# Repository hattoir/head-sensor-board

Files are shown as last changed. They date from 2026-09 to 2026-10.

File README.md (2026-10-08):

# 🧠 Serpens Head Sensor Board

> Prototype head sensor PCB for the Serpens snake-shaped pet robot.

Serpensの頭部に搭載するために設計している、
**試作用センサ基板**です。

XIAO ESP32S3 Senseを中心に、

- VL53L1X ToFセンサ ×2
- NSSW157T 白色LED ×2
- MOSFET PWM駆動
- I2C
- Test Points
- 外付けLEDヘッダ

をまとめています。

主な目的は、

- 床端・崖の検出
- 頭部周辺の距離センシング
- LEDによる表現・照明試験

です。

> ⚠️ 現在は設計・製造データ生成まで完了していますが、
> 実基板はまだ発注・製造していません。

---

## 📊 Current Status

| Area | Status |
|---|---|
| Specification | ✅ Complete |
| Schematic | ✅ ERC 0 |
| PCB Layout | ✅ Complete |
| Routing | ✅ Complete |
| DRC | ✅ 0 violations |
| 3D Render | ✅ Complete |
| Gerber / Drill | ✅ Generated |
| BOM | ✅ Generated |
| Manufacturing | ⚪ Not ordered |
| Hardware Verification | ⚪ Not tested |

---

## 🖼 PCB Preview

<!-- ここに今ある3Dレンダリング画像 -->

### Top / Angle View

Head Sensor Board

> ※ 実物写真ではなく、KiCad上の3Dレンダリングです。

---

## ⚙️ Main Components

- XIAO ESP32S3 Sense
- VL53L1X ×2
- NSSW157T ×2
- AO3400A / MOSFET
- I2C pull-up
- Test points

---

## 📐 Board

- Size: **44 × 28 mm**
- Layers: **2**
- M2 mounting holes ×2
- GND plane on both layers
- USB-C access from board edge
- ToF headers on long edges
- LED / external LED headers on right side

---

## 🔬 Verification

現在までに、

- ERC: 0 errors
- DRC: 0 violations
- Unconnected: 0
- Schematic / PCB mismatch: 0
- Silkscreen clearance check
- Gerber verification

を行っています。

ただし、
実機に接続しての電源・ToF・LED動作確認は未実施です。

---

> ## ⚠ 電源の運用上の注意（User 指示 2026-10-01。回路図の注記 H にも同じ内容）
> 1. **5V は試験用の選択肢で、既定は 3V3。** 5V にしたときの合計 **493 mA は USB 2.0 の 500 mA ぎりぎり**（余裕 7 mA）。XIAO の 5V ピンの電流能力は未確認。
> 2. **3V3 は、Wi-Fi 送信・撮影・LED 100 %・ToF ピークを同時にしない運用が必要。** **実機で XIAO の 5V 入力電流を測るまで。**（Seeed の条件不明の 0.65 A を上限と見ると 3V3 の合計は 808 mA = Seeed の「700 mA」の 115 %。[docs/spec.md](docs/spec.md) §4.3）

## 進み具合

| Stage | 内容 | 状態 |
|---|---|---|
| 1 | 仕様と部品表 | 完了（2026-10-01、承認済み） |
| 2 | 回路図と ERC（エラー 0） | 完了（2026-10-01、User 確認済み。ERC 0 件） |
| 3 | 外形と部品配置案（配線なし） | 完了（2026-10-01、User 確認済み） |
| 4 | 外形 44×28 mm、配線、DRC（違反 0・未接続 0・回路図との不一致 0）、3D ビュー、製造データ | **完了（2026-10-02）。製造データ（ガーバー・ドリル・位置ファイル・BOM、ZIP）は [gerbers/](gerbers/) に出した。User の最終確認待ちで、発注はしていない**（[docs/spec.md](docs/spec.md) §6・§7） |

## 配線後の配置（Stage 4）

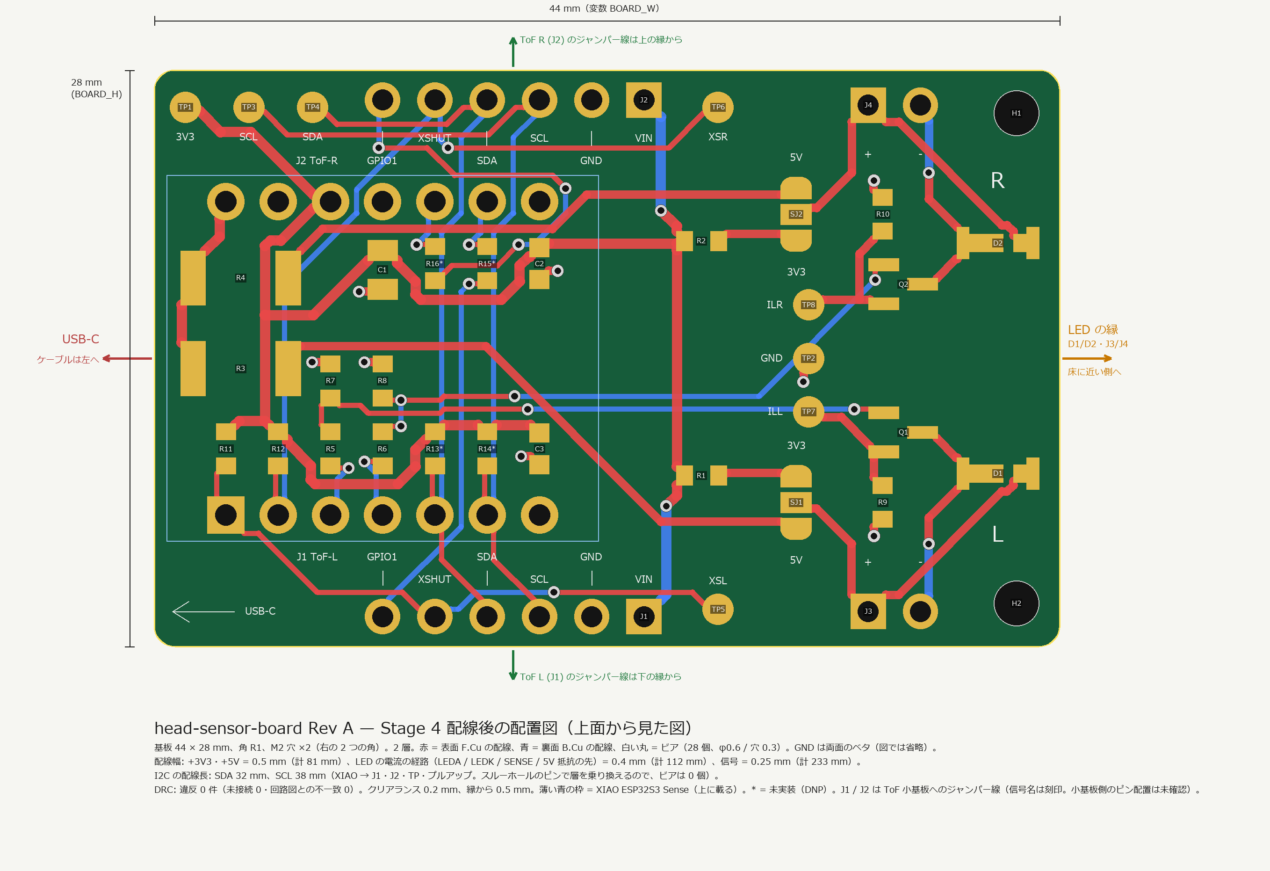
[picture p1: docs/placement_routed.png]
配線後の配置図


- **44 × 28 mm、角 R1、M2 穴 ×2**（右の 2 つの角、縁から 2.1 mm）。2 層。`python tools/make_board.py --width W --height H` で、外形・配置・配線・DRC まで作り直せる（[再生成と検証](#再生成と検証)）。
- **USB-C は左の縁**（左下に矢印と「USB-C」の刻印）、**LED（D1/D2）と外付け LED ヘッダ（J3/J4）は右寄りの縁**、**ToF ヘッダ（J1/J2）は上下の長辺の縁**（6 本の信号名を刻印）、TP は上面。**「L」「R」の刻印**あり。
- **下半分 = L チャンネル、上半分 = R チャンネル**（上面から見て USB-C を左にしたとき）。基板上の L/R はロボットの左右とは限らない（ジャンパー線で左右は自由に決められる）。
- 配線: **電源（+3V3・+5V）0.5 mm、LED の電流の経路 0.4 mm、信号 0.25 mm**。GND は両面のベタ。ビア 28 個。I2C の長さは SDA 32 mm・SCL 38 mm。
- **DRC: 違反 0 件**（クリアランス 0.2 mm・縁 0.5 mm・未接続 0・回路図との不一致 0。プロジェクトで「無視」にしていた 4 種の検査も有効にして 0 件）。[docs/drc_report.txt](docs/drc_report.txt)
- **刻印の検査**（`tools/check_board.py`）: 上面の刻印 137 個が、ランド・ほかの刻印と **0.15 mm 以上**、ヘッダの樹脂部（2.54 mm 角）と 0.05 mm 以上、XIAO の外形・基板の縁と離れている。**シルクの線は全部 0.15 mm 以上、文字の高さは 0.8 mm**（2026-10-05 に 0.12 → 0.15 mm に直した。発注先 4 社の公開仕様との照合 → [docs/fab_check.md](docs/fab_check.md)。**JLCPCB の標準の文字（高さ 1.0 mm 以上）だけは未達で、注文画面の「高精度の文字」を選べば通る**。PCBWay・Elecrow・Seeed Fusion は通る）。J1/J2 の信号名は樹脂部の外に 2 段で置き、奥の段には樹脂部の手前までの引き出し線を引いた。
- XIAO の下（ソケットの内側）に小さい部品を置き、裏面は GND ベタ。Sense 拡張ボード（カメラ・microSD）は XIAO の上面に載り、基板側の部品とは干渉しない（出っ張りは未確認。[docs/spec.md](docs/spec.md) §6.5）。

| | |
|---|---|
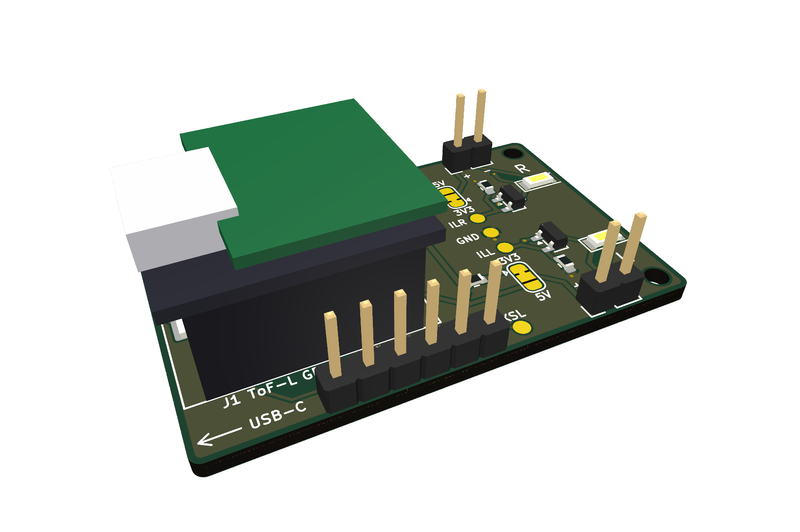
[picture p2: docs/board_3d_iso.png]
3D（斜め）
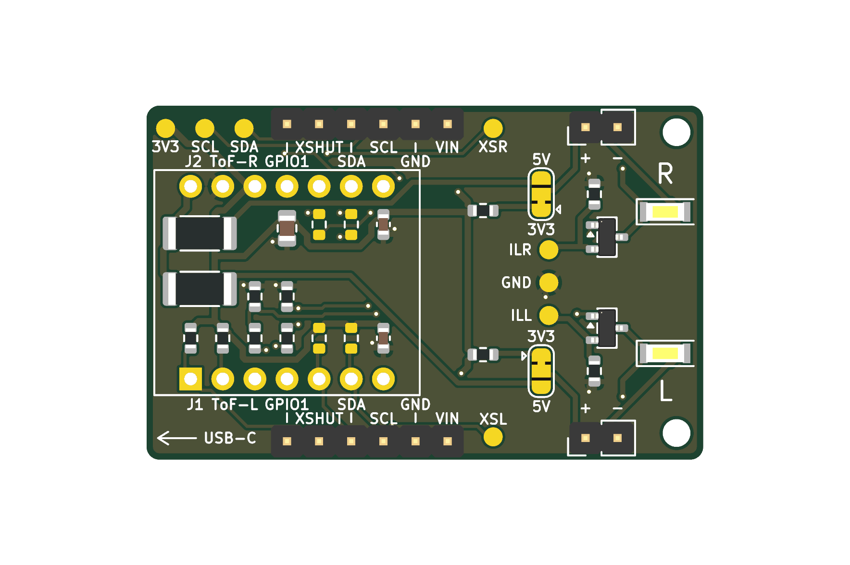
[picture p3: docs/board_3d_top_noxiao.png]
3D（XIAO なし）
|  |  |
| 斜め上から（XIAO・拡張ボードは**簡易な箱**。高さは仮） | 真上から（XIAO を外した状態） |

そのほか: [層ごとの配線](docs/routing_layers.png)（表面 F.Cu・裏面 B.Cu）、[3D 真上](docs/board_3d_top.png)、[3D 裏面](docs/board_3d_bottom.png)。

## ToF 小基板のピン配置と、ジャンパー線の対応表（**現物が届いたら埋める**）

J1 / J2 の 6 本は、ToF 小基板（VL53L1X、Amazon B083Z316NC）へジャンパー線でつなぐ。**小基板のピン配置は販売ページに記載がなく、未確認。** ヘッダの並び（上面に信号名を刻印）は仮で、**小基板の並びが違っても基板の作り直しは要らない**（線でつなぎ替える）。J1 = ToF L（下の縁）、J2 = ToF R（上の縁）。pin1 は右端（上面から見て、VIN）。

### J1 / J2 の向き（Stage 3 から 180° 回した理由）と確認結果

- **ピン 1（四角いパッド）は右端**（上面から見て USB-C を左にしたとき）。刻印の並びは**右から** VIN, GND, SCL, SDA, XSHUT, GPIO1（左から読むと GPIO1, XSHUT, SDA, SCL, GND, VIN）。J1 と J2 は同じ向き・同じ x（ピン 1 = 基板の左端から 23.8 mm）。
- Stage 3 ではピン 1 が左端だった。**Stage 4 で 180° 回した理由**: XIAO では SDA（D4）が SCL（D5）の左にある。ヘッダも SDA が SCL の左になる向きにすると、I2C の線が交差せずに、層の乗り換え（ビア）も減る。ヘッダの**信号の割り当て（pin1 = VIN … pin6 = GPIO1）は回路図のまま変えていない**（並べ替えは物理的な向きだけ）。ジャンパー線で小基板につなぐので、向きは線の取り回しにしか影響しない。
- 確認（`python tools/check_board.py`、基板を直接読む）: J1/J2 の 6 パッドすべてで、**基板のネット = 回路図のネット = 刻印の名前**（pin1 +3V3/VIN、pin2 GND、pin3 SCL、pin4 SDA、pin5 XSHUT_L/R、pin6 TOF_L_INT/TOF_R_INT/GPIO1）。四角いパッドは pin1 だけ。

### 小基板の仕様（現物で確認して埋める）

| 項目 | 値 | 確認 |
|---|---|---|
| 基板上の印字（ピンの名前、端から順に） | （現物で確認） | 🔴 未確認 |
| ピンの数・ピッチ・オス/メス | （現物で確認） | 🔴 未確認 |
| 電源電圧 | 3.3〜5 V（商品ページの記載） | 🟡 |
| 基板上のプルアップ（SDA / SCL / XSHUT）、レギュレータ、レベルシフタの有無 | （現物で確認） | 🔴 未確認 |
| I2C アドレス | ST のデータシートの既定は 0x29（7 bit）。**小基板で変わるかは未確認** | 🟡 |

### 対応表（J1 / J2 のピン ↔ 小基板のピン）

| J1 / J2 のピン | 基板の信号名 | つなぎ先 | 小基板のピン（印字）→ **現物で記入** | ジャンパー線 | メモ |
|---|---|---|---|---|---|
| 1 | VIN | XIAO の 3V3 | （　　　　） | （　　　　） | 小基板が 3.3〜5 V 対応なので 3V3 を使う。**VIN と GND を逆につながない**（小基板の保護は未確認） |
| 2 | GND | GND | （　　　　） | （　　　　） | |
| 3 | SCL | I2C SCL（D5） | （　　　　） | （　　　　） | プルアップは基板側 R14（3.3 kΩ、既定は未実装）か小基板側 |
| 4 | SDA | I2C SDA（D4） | （　　　　） | （　　　　） | 同 R13（既定は未実装） |
| 5 | XSHUT | J1: XSHUT_L（D0）／J2: XSHUT_R（D1） | （　　　　） | （　　　　） | 10 kΩ で 3V3 にプルアップ済み |
| 6 | GPIO1 | J1: R15 経由で D8／J2: R16 経由で D9 | （　　　　） | （　　　　） | R15/R16（0 Ω）は**既定で未実装**（つながない）。割り込みを使うときだけ実装 |

**2 個の小基板は I2C アドレスが同じ**なので、XSHUT で 1 個ずつ起動して、片方のアドレスを変える（[docs/spec.md](docs/spec.md) §3）。

## フォルダ構成

| 場所 | 中身 |
|---|---|
| （直下） | KiCad プロジェクト（`.kicad_pro` / `.kicad_sch` / `.kicad_pcb`、`sym-lib-table` / `fp-lib-table`） |
| `.ai/` | 閉ループの記録（`CURRENT_HANDOFF.md`、`PROJECT_STATE.json`、`TASK_GRAPH.json`、`DECISIONS.jsonl`、`EXPERIMENTS.jsonl`、`EVIDENCE.jsonl`。追記専用の `.jsonl`）。次のセッションはここから再開する |
| `docs/` | [spec.md](docs/spec.md)（仕様・計算・配置・配線・検証）、[fab_check.md](docs/fab_check.md)（発注先の公開仕様との照合）、[bringup_plan.md](docs/bringup_plan.md)（届いてからの確認手順 = Human Gate）・[bringup_nets.md](docs/bringup_nets.md)（導通の確認表）、[bom.md](docs/bom.md)・`bom.csv`（部品表。**Stage 2 のまま**。BOM の出力時に再生成）、`erc_report*.txt`・`drc_report.txt`、回路図 PDF、配線後の配置図・層ごとの配線・3D ビュー（PNG）、`routes.json`（配線の結果）、`led_budget_output.txt` |
| `libs/` | 自作のシンボル・フットプリント（**KiCad 標準ライブラリに無いものだけ**。下の「ライブラリの出典」） |
| `3dmodels/` | 3D ビュー用の**簡易モデル**（`.wrl`。XIAO + Sense 拡張ボード、LED の箱）。`tools/gen_3d.py` で生成。見た目の確認用 |
| `gerbers/` | **製造データ**（ガーバー、ドリル、位置ファイル、BOM、`head-sensor-board_gerbers.zip`、README）。2026-10-02 に出した。**発注はしていない**（User の最終確認のあと）。中身の説明は [gerbers/README.md](gerbers/README.md) |
| `tools/` | 計算・生成・検証のスクリプト（下の「再生成と検証」） |

## 数値・部品名の出典

確認状態: ✅ 原本（データシート・公式図面）で確認 ／ 🟡 販売ページ・Wiki で確認 ／ 🔴 未確認・仮定。**確認できていないものは、`docs/spec.md` の各表に「未確認」と書いてある。**

| 対象 | 出典 | 確認 |
|---|---|---|
| NSSW157T（Nichia）: 外形 3.0×1.4×0.52、VF、IF max、推奨ランド | [Nichia STS-DA1-1913（秋月配布 PDF）](https://akizukidenshi.com/goodsaffix/nssw157t.pdf)、[秋月 116884](https://akizukidenshi.com/catalog/g/g116884/) | ✅ |
| AO3400A（Alpha & Omega）: VGS(th)、RDS(on) @2.5 V、SOT-23 | [AOS データシート Rev 3.1](https://www.aosmd.com/res/data_sheets/AO3400A.pdf) | ✅ |
| Si2302CDS（Vishay）: VGS(th)、RDS(on) @2.5 V、1=G 2=S 3=D | [Vishay 68645（S12-2336 Rev D）](https://www.vishay.com/docs/68645/si2302cds.pdf) | ✅ |
| VL53L1X（ST）: AVDD 2.6〜3.5 V、消費電流、XSHUT・I2C・既定アドレス、最短 4 cm | ST DS12385 Rev 8（[複製 PDF](https://www.makerguides.com/wp-content/uploads/2024/10/VL53L1X-Datasheet.pdf)。ST 公式サイトの版では未照合） | ✅（複製） |
| ESP32-S3: Wi-Fi 送信ピーク 340 mA、GPIO の IOH/IOL、VOH、GPIO3 ストラッピング | [Espressif ESP32-S3 Datasheet v2.2](https://www.espressif.com/sites/default/files/documentation/esp32-s3_datasheet_en.pdf)（表 5-7・表 5-4・§3.4） | ✅ |
| XIAO ESP32S3: ピン配置、GPIO 番号、3V3 出力 700 mA、Webcam の消費電流、Sense が使う GPIO | [Seeed wiki](https://wiki.seeedstudio.com/xiao_esp32s3_getting_started/)（PDF のデータシートは見つからず） | 🟡 |
| XIAO の穴パターン（ピッチ 2.54、行間隔 15.25、穴 φ1.02、外形 21×17.8） | [Seeed "XIAO Series Package and PCB Design" p.7](https://www.seeedstudio.com/blog/wp-content/uploads/2022/08/Seeed-Studio-XIAO-Series-Package-and-PCB-Design.pdf)（シリーズ共通図。S3 個別ではない） | ✅（共通図） |
| VL53L1X 小基板（Amazon B083Z316NC）: 12×17×3.2 mm、3.3〜5 V | [商品ページ](https://www.amazon.co.jp/dp/B083Z316NC)。**ピン配置・プルアップ・アドレスの記載なし** | 🔴 |
| 頭の外形 幅 100 / 高さ 74 / 長さ 78 mm、ToF・LED の位置 | `serpens/ai-shared/design-state.md`、`serpens/docs/design/tof_board_placement_2026-09-30.md`（Design の概念値 = CAD_CONCEPT / ASSUMED） | 🔴（概念値） |
| T6 / T4 の試験の内容 | `serpens/ai-shared/HARDWARE_TODO.md` HT-005 / HT-011、HG-H2 の `hardware_test_plan.md`・`tof_cliff.md`（Engineering の worktree `agent/engineering-h1-j1`、未マージ） | 🟡 |

## ライブラリの出典

`libs/` にあるのは、KiCad 標準ライブラリに無い（または標準を少し変えた）7 点だけ（`python tools/gen_libs.py` で生成）。

| 名前 | 種類 | 理由 | 出典 |
|---|---|---|---|
| `XIAO_ESP32S3` | シンボル（14 ピン。電源ピンを上下に置いた表示。ピン番号は実物のまま） | 標準ライブラリに XIAO ESP32S3 が無い | ピン配置は Seeed wiki |
| `ToF_Header_1x06` | シンボル（ピン名つき。**並びは仮 = 未確認**） | ピン名（VIN, GND, SCL, SDA, XSHUT, GPIO1）を回路図に出すため | 自作 |
| `Q_NMOS_GSD` | シンボル（SOT-23 の 1=G 2=S 3=D） | 標準の `Device:Q_NMOS` はピン番号が D/G/S の文字で、SOT-23 のパッド番号と合わない | 図形は KiCad 標準 `Device:Q_NMOS` を流用、ピン番号だけ数字に |
| `XIAO_ESP32S3_THT_2x7_P2.54mm` | フットプリント（穴パターン） | 標準には表面実装用の `RF_Module:MCU_Seeed_ESP32C3` しか無く、2.54 mm の穴パターンが無い | Seeed 公式図面 p.7（行間隔 15.24 mm = 図面の 15.25 を 0.6 in に丸めた、穴 φ1.02、パッド φ1.8）。**コートヤードはピン列の帯だけ**（XIAO の下に小さい部品を置くため。Stage 3） |
| `TestPoint_Pad_D1.5mm_NoSilk` | フットプリント（TP） | 標準の `TestPoint:TestPoint_Pad_D1.5mm` の銀色の輪（半径 0.95 mm）が、近くに置く名前の刻印と重なるため | KiCad 標準 `TestPoint_Pad_D1.5mm` から輪だけ除いた（パッド φ1.5、コートヤード 半径 1.05）。Stage 3 |
| `PinHeader_1x06_P2.54mm_NoSilk` | フットプリント（J1/J2。ToF ヘッダ） | 標準の `Connector_PinHeader_2.54mm:PinHeader_1x06_P2.54mm_Vertical` の上面シルクの外枠が、6 本の信号名の刻印と重なるため | KiCad 標準から**上面シルクの外枠（線・四角）だけ除いた**（ランド・穴・コートヤード・Fab・3D は標準のまま）。Stage 4 |
| `LED_Nichia_NSSW157T` | フットプリント（T 字のランド） | 標準ライブラリに同寸法のものが無い | Nichia STS-DA1-1913 p.4–5（全長 4.0、カソード 0.6+1.66、ギャップ 0.5、アノード 0.64+0.6、高さ 1.55/0.86） |

3D モデル: 標準ライブラリにある部品（ピンヘッダ、抵抗、MOSFET など）は標準のモデル。**XIAO + Sense 拡張ボードと NSSW157T は `3dmodels/` の簡易な箱**（高さは仮。見た目の確認用で、寸法の根拠にしない）。

## 再生成と検証

```bash
python tools/led_budget.py        # LED 電流・3V3/5V の総電流の計算（docs/led_budget_output.txt）
python tools/gen_libs.py          # 自作ライブラリ（libs/）と sym-lib-table / fp-lib-table
python tools/gen_3d.py            # 簡易 3D モデル（3dmodels/）
python tools/gen_schematic.py     # 回路図（※KiCad で手直しした後は実行しない。手直しが消える）
python tools/check_netlist.py     # ネットリストを期待と照合、回路図のピン番号がフットプリントのパッドに存在するか
python tools/make_board.py [--width 44 --height 28] [--reuse-routes]
                                  # 外形・配置（gen_pcb.py）→ 自動配線（route.py、numpy + scipy）→ トラック・ビア・GND ベタ（apply_routes.py）→ DRC。
                                  # ※既存の基板を作り直す（KiCad で手で直した配線は消える）。約 30 秒
                                  # --reuse-routes: ランドの位置を変えず刻印だけ直したとき、配線をやり直さない（DRC で整合を確かめる）。自動配線は約 1〜10 分（CPU が空いていれば 1 分以内）
"C:/Program Files/KiCad/10.0/bin/python.exe" tools/check_board.py   # J1/J2 のネット・パッド・刻印の照合、刻印のすきまの検査（問題があれば終了コード 1）
"C:/Program Files/KiCad/10.0/bin/python.exe" tools/render_routed.py   # 配線後の配置図・層ごとの配線（docs/*.png）
python tools/render_3d.py         # KiCad の 3D ビュー（docs/board_3d_*.png）
python tools/make_outputs.py [--bom]   # ERC・DRC・回路図 PDF・BoardRepo 用 zip（--bom で BOM も）
python tools/make_fabrication.py  # gerbers/（ガーバー・ドリル・位置ファイル・BOM・ZIP）。**User の確認のあとにだけ**
python tools/verify_gerbers.py    # 出力した ZIP を別のライブラリ（gerbonara）で読み直して、基板と照合（pip install gerbonara）
python tools/compare_gerbers.py --current   # gerbers/ が今の基板から作り直した図形と同じか（古くなっていないか）。2 つの ZIP / git の ref の比較にも使える
"C:/Program Files/KiCad/10.0/bin/python.exe" tools/check_fab_rules.py [--md docs/fab_check.md]   # 発注先 4 社の公開仕様（tools/fab_rules.json）との照合
python tools/gen_bringup_tables.py   # 導通の確認表 docs/bringup_nets.md（回路図から）
python tools/run_all_checks.py    # 上の検査を全部まとめて回す（何も書き換えない。発注の前に）
```
KiCad は `C:/Program Files/KiCad/10.0/bin/kicad-cli.exe`（PATH には入っていない）。`tools/pcb_template.kicad_pcb` は空の基板（層・設定だけ。`gen_pcb.py` が毎回ここから作る）。
自動配線は KiCad の Python に scipy が無いため、基板の形状を `docs/placement_geometry.json` に書き出し → システムの Python で配線 → `docs/routes.json` → KiCad の Python で基板に書き戻す、の 3 段。

## BoardRepo について

- BoardRepo は「アップロードのたびに番号つきの版ができる」方式で、閲覧・MCP は OAuth のサインインが要る（[boardrepo.com](https://boardrepo.com)）。**Agent 側からは取り込みを確認できない。User が手動でアップロードする。**
- `snake-main-board` の GitHub リポジトリにも、BoardRepo の Webhook・チェック・コミットステータスは残っていない（確認済み）。
- **アップロード用の束**: `C:\2026\Serpens_Home AI\head-sensor-board_upload.zip`（`tools/make_outputs.py` が作る。Git には入れない）。中身: `.gitignore`、`README.md`、`.kicad_pro`、`.kicad_sch`、`.kicad_pcb`（**Stage 4: 44×28 mm、配線済み・GND ベタ。ガーバーではない**）、`sym-lib-table`、`fp-lib-table`、`libs/`（自作ライブラリ）、`3dmodels/`（簡易 3D モデル）。別フォルダに展開して、ERC 0 件・DRC 0 件になることを確認する（make_outputs 後に実施）。
- **アップロードして表示できたかは User の確認が要る。**

## 注意

- `*-backups/`、`fp-info-cache`、`*.kicad_prl`、ロックファイル、自動保存、`*_upload.zip` は Git に入れない（`.gitignore`）。
- このフォルダは、親の `serpens`（ロボット制御のリポジトリ）とは**別の Git リポジトリ**（入れ子）。親側は `.git/info/exclude` で無視している。`snake-main-board` とも別。

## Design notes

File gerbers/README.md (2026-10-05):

# gerbers/ — head-sensor-board Rev A の製造データ

**未発注。User の最終確認のあとに発注する**（発注は Agent はしない）。Stage 4 の PNG を User が確認した後に `python tools/make_fabrication.py` で作った（KiCad 10.0.1 の `kicad-cli`）。
基板を直したら、`python tools/make_board.py` → `python tools/make_outputs.py --bom` → `python tools/make_fabrication.py` の順で作り直す（このフォルダのファイルは毎回消して作り直される。手で直さない）。

## 発注先に渡すもの

**`head-sensor-board_gerbers.zip`**（ガーバー 8 層 + ジョブファイル + ドリル 2 本 = 11 ファイル）。

## ファイル

| ファイル | 内容 |
|---|---|
| `*-F_Cu.gtl` / `*-B_Cu.gbl` | 表・裏の銅（GND のベタを含む） |
| `*-F_Mask.gts` / `*-B_Mask.gbs` | 表・裏のレジスト開口（ランドと同寸。ビアはふさぐ） |
| `*-F_Silkscreen.gto` / `*-B_Silkscreen.gbo` | 表・裏のシルク（表: 部品の枠・信号名・L/R・USB-C、裏: 凡例） |
| `*-F_Paste.gtp` | 表のはんだペースト（ステンシルを作るときだけ。手はんだなら不要） |
| `*-Edge_Cuts.gm1` | 外形（角 R1 の長方形） |
| `*-PTH.drl` / `*-NPTH.drl` | ドリル（Excellon、mm）。PTH = めっきあり、NPTH = めっきなし（M2 の取付穴） |
| `*-job.gbrjob` | ジョブファイル（層の構成・寸法） |
| `*-PTH-drl_map.pdf` / `*-NPTH-drl_map.pdf` | ドリルの位置図（目で確かめる用。発注先には要らない） |
| `head-sensor-board_pos.csv` | 位置ファイル（**表面実装で、実装するもの**だけ。DNP の R13〜R16 は含まない。mm、原点は基板の左下、Y は上が +） |
| `head-sensor-board_BOM.csv` | BOM（`docs/bom.csv` と同じ。読みやすい版は `docs/bom.md`） |
| `SHA256SUMS.txt` | 各ファイルのハッシュ（手元で改変していないことの確認用） |

**原点はすべて基板の左下**（ガーバー・ドリル・位置ファイルで共通）。

## 基板の仕様（発注フォームに入れる値。**発注先の仕様との照合は User が行う**）

| 項目 | 値 |
|---|---|
| 層数 | 2 層 |
| 寸法 | 44.0 × 28.0 mm（角 R1.0） |
| 厚み | 1.6 mm |
| 銅厚 | 基板データには指定なし。標準の 1 oz（35 µm）を想定（線の許容電流の目安もこれ） |
| 表面処理 | 指定なし（はんだ付けは手作業。XIAO・ヘッダのスルーホールと 0603 / 2010 / SOT-23 / NSSW157T） |
| 最小線幅 / 最小間隔 | 使った線幅は 0.25 / 0.4 / 0.5 mm（設計の下限 0.2）、間隔 0.2 mm 以上 |
| 銅と外形の距離 | 0.5 mm 以上 |
| ビア | 外径 0.6 mm / 穴 0.3 mm、レジストでふさぐ（テンティング） |
| 穴 | PTH φ0.3 mm × 28、PTH φ1 mm × 16、PTH φ1.02 mm × 14、NPTH φ2.2 mm × 2 |
| レジスト | 開口はランドと同寸（拡張 0）。多くの発注先は自分で拡張をかける。色は任意 |
| シルク | 線幅 **0.15 mm**（部品の枠を含む全部）、文字の高さ **0.8 mm**。**JLCPCB の標準は文字の高さ 1.0 mm 以上なので、JLCPCB で発注するときは注文画面の「高精度の文字」（0.8 mm 以上）を選ぶ**（追加費用の有無は未確認）。PCBWay・Elecrow・Seeed Fusion は 0.8 mm・0.15 mm で可。**4 社の公開仕様との照合は `docs/fab_check.md`**（2026-10-05 に公開ページから取った値。注文して確かめたものではない） |
| 数量 | User が決める |

## 注意

- **NSSW157T（D1/D2）はリフローかホットエアで付ける部品**（フットプリントの注意書きどおり。樹脂を押さない）。
- J1/J2 は ToF 小基板へのジャンパー線用のヘッダ。**小基板のピン配置は未確認**（README の対応表を現物で埋める）。信号名のシルクと基板の配線は、回路図と一致することを確認済み（`tools/check_board.py`）。
- 検証: `python tools/verify_gerbers.py`（KiCad とは別の gerbonara で、zip の中身を読み直して、外形・ドリルの位置と径・銅の抜けを基板と照合する。`pip install gerbonara` が要る）。`python tools/compare_gerbers.py --current` は、このフォルダが今の基板から作り直したものと同じ図形か（古くなっていないか）を確かめる。`python tools/run_all_checks.py` で全検査をまとめて回せる。結果は `docs/spec.md` §7。
- 届いてからの手順（外観・導通・初回通電・LED 電流・ToF）は `docs/bringup_plan.md`。

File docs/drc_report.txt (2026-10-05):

** Drc report for head-sensor-board.kicad_pcb **
** Created on 2026-10-05T18:53:41 **
** Report includes: Errors, Warnings, Exclusions **

** Found 0 DRC violations **

** Found 0 unconnected pads **

** Found 0 Footprint errors **

** Ignored checks **
    - Tuning profile track geometries

** End of Report **

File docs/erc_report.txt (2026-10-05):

ERC report (2026-10-05T18:53:34, Encoding UTF8)
Report includes: Errors, Warnings, Exclusions

***** Sheet /

 ** ERC messages: 0  Errors 0  Warnings 0

 ** Ignored checks:
    - Global label only appears once in the schematic
    - Four connection points are joined together
    - SPICE model issue
    - Assigned footprint doesn't match footprint filters

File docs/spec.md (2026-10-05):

# head-sensor-board — 仕様と部品表（Stage 4 更新版）

**Floor Watch の「頭のセンサー基板（試作用）」。** ToF の崖判定（HG-H2 の T6-1〜T6-4）と、斜め LED の追試（T4）に使う。**本番の基板ではない。**
状態: **Stage 4（44×28 mm、配線、DRC 違反 0）+ 製造データ（`gerbers/`）を出した（2026-10-02）。User の最終確認待ちで、発注はしていない。** 回路図は ERC 0。ToF 小基板のピン配置が未確認でも、ジャンパー線でつなぐので基板のガーバーは出せる（User 指示 2026-10-01）。

確認状態の印: ✅ 原本（データシート・公式図面）を読んで確認 ／ 🟡 販売ページ・Wiki で確認（原本は未確認）／ 🔴 未確認・仮定 ／ ⚪ 資料に記載なし

## 運用上の注意（User 指示 2026-10-01。README と回路図の注記 H にも同じ文を残した）

1. **5V は試験用の選択肢で、既定は 3V3。** 5V にしたときの合計 **493 mA は USB 2.0 の 500 mA ぎりぎり**（余裕 7 mA）。5V の取り出しは、半田ジャンパー SJ1/SJ2 の 5V 側パッドだけ（既定では開放）。XIAO の 5V ピンの電流能力は未確認。
2. **3V3 は、Wi-Fi 送信・撮影・LED 100 %・ToF ピークを同時にしない運用が必要。** 実機で XIAO の 5V 入力電流を測るまで（§4.3。Seeed の条件不明の 0.65 A を上限と見ると 808 mA = 700 mA の 115 %）。
3. **ToF 小基板のピン配置は未確認**（ヘッダの並びは仮）。ジャンパー線でつなぐので、並びが違っても基板は作り直さない（README の対応表を現物で埋める）。

## 0. Stage 1 からの変更点（User の回答 2026-10-01 を反映）

| # | User の回答 | この版での扱い |
|---|---|---|
| 1 | 外形 **40×25 mm**（角 R1、M2 穴 2 個）、変数で作り直せるように。頭（幅 100 × 高さ 74 × 長さ 78 mm、`design-state.md` の Bean 頭）に収まる。**ToF は基板に直付けせず、ジャンパー線で離して置く**（1×6 ヘッダから引き出す） | 外形は Stage 3 で `BOARD_W`/`BOARD_H` の変数で作る。ToF は 1×6 ヘッダ（J1/J2）+ ジャンパー線 12 本 |
| 2 | **高さ 6 mm 以下は LED だけ**。LED は基板上（D1/D2）+ 外付け用ヘッダ（L/R 各 2 本: +, −）。ほかの部品は制限なし | D1/D2（0.52 mm ✅）と、外付けヘッダ J3/J4 を追加。§6 |
| 3 | ToF のピン配置は現物が届くまで確定しない。**Stage 3 まで進め、ガーバーは出さない**。並びは仮、README に「未確認」 | シンボルとヘッダの並びを「仮（PLACEHOLDER）」と明記。README・回路図・BOM にも書いた |
| 4 | LED は 3V3・20 Ω（公称 約 30 %）で進める。**LED の電源を半田ジャンパーで 3V3（既定）/ 5V に切替**。5V 側の抵抗は 1206 以上で再計算。MOSFET のゲートが 3.3 V ロジックで駆動できることを確認 | SJ1/SJ2 + R3/R4（**33 Ω 2010**）。§4。MOSFET は AO3400A / Si2302CDS の原本で確認（§4.4） |
| 5 | 3V3 の電流の合計を、Wi-Fi・カメラのピークも含めて再計算 | §4.3 |
| 6 | GPIO 割り当ては承認（D0=XSHUT_L, D1=XSHUT_R, D2=LED_L PWM, D3=LED_R PWM, D4=SDA, D5=SCL, D6/D7=UART 予約、5V ピンは未接続）。integration-log に ENTRY（TO: Engineering） | §3。ENTRY-K-0001 |
| 7 | 追加購入（MOSFET ×2、抵抗・コンデンサ、ピンソケット・ピンヘッダ）は承認。品番・価格は User が調べる | [bom.md](bom.md)（型番・パッケージ・定格を書き出した） |
| 8 | **Stage 4（2026-10-01）**: 外形は **44×28 mm**（Stage 3 の 40×25 から。余裕ができた）、L/R・USB-C・J1/J2 の信号名を刻印、Sense 拡張ボードの張り出しを確認、穴の位置はそのまま、ToF のピン配置が未確認でもガーバーは止めない | §6 |

**解釈の注意（2 点）**
- **「5V ピンは未接続」と「LED 電源に 5V も選べる」は、そのままだと両立しない。** そこで「XIAO の 5V ピンは、半田ジャンパー SJ1/SJ2 の 5V 側パッドにだけつながる（既定では開放 = 電気的には未接続）」と解釈した。5V ピンを LED に使う場合だけ、User が半田でつなぐ。この解釈が違えば指示してほしい。
- Stage 1 の LED 電流は 公称 23.7 mA だったが、MOSFET の Rds(on) の仮定を 0.05 → 0.075 Ω（Si2302CDS の最大）に直したため **23.6 mA** になった（最小/最大は同じ 8.5 / 38.8 mA）。訂正ではなく仮定の更新。

## 1. 仕様

| 項目 | 内容 |
|---|---|
| 電源 | **既定: XIAO の 3V3 ピンだけ**。5V ピンは SJ1/SJ2 の 5V パッド（既定では開放）だけにつながる |
| マイコン | XIAO ESP32S3 Sense（U1）を、2×7 のピンソケット（またはピンヘッダ）で載せる。直付けしない。2.54 mm ピッチ、穴の行間隔 15.24 mm |
| ToF | VL53L1X 小基板 ×2。**1×6 ヘッダ J1/J2（VIN, GND, SCL, SDA, XSHUT, GPIO1）からジャンパー線で引き出す**（並びは仮）。XSHUT を GPIO から個別制御。GPIO1 は 0 Ω リンク（DNP）で D8/D9 につなげる |
| LED | NSSW157T ×2（D1/D2、基板上）。電流制限抵抗 + N-ch MOSFET でスイッチ、GPIO から PWM 調光。**外付け LED 用ヘッダ J3/J4（pin1 = +、pin2 = −）**。D1/D2 か外付けの**どちらか一方**を使う（両方だと電流を分け合う） |
| LED の電源 | 各チャンネル 3 パッドの半田ジャンパー（SJ1/SJ2）。**既定は 1-2 をつないだ状態 = 3V3（R1/R2 = 20 Ω 0603）**。5V にするときは 1-2 の橋を切り、2-3 をはんだでつなぐ（R3/R4 = 33 Ω 2010 は実装済み） |
| I2C プルアップ | R13/R14（3.3 kΩ）を置き、**既定は未実装（DNP）**。XSHUT のプルアップ（10 kΩ）は実装 |
| テストポイント | TP1 3V3、TP2 GND、TP3 SCL、TP4 SDA、TP5 XSHUT_L、TP6 XSHUT_R、TP7 ILED_L、TP8 ILED_R（電流の電圧 = 1 mV/mA） |
| 基板 | 2 層、1.6 mm。**外形 44×28 mm（角 R1、M2 穴 2 個）、変数で作り直せるように**（Stage 3 は 40×25）。KiCad 10.0.1 |

**LED チャンネルの回路（L / R 同じ）**
```
 +3V3 ─ R1(20Ω 0603) ─┐ 1
                       SJ ─2─ LEDA ─┬─ D(NSSW157T) ─┬─ LEDK ─ Q(AO3400A).D
 +5V  ─ R3(33Ω 2010) ─┘ 3           └─ J(+)          └─ J(−)            G ← 220Ω ← GPIO(PWM)、100kΩ で GND
                                                                          S ─ SENSE ─ R(1Ω) ─ GND   （TP ILED = SENSE）
```
J3/J4 のピンは抵抗の**あと**のノード（電流制限済み）。**J3/J4 の + と − を短絡しない**（R1 が約 0.49 W、R3 が約 0.71 W を消費して焼ける）。

## 2. 読んだ資料

| 資料 | 分かったこと |
|---|---|
| `serpens/ai-shared/design-state.md` | 頭は Bean 形: **幅 100 × 高さ 74 × 長さ 78 mm**（概念値。CAD_CONCEPT / ASSUMED）。ToF 小基板は横スキッド前端「肉球」（\|y\| 37.8〜49.8、z 3.0〜6.2）、LED は同じ前端（X −228、\|y\| 40、Z 4.5）。**基板の寸法制限の記載はない** → User が 40×25 mm で承認 |
| `serpens/ai-shared/interface-contract.md` | 役割分担の取り決めだけ。寸法の記載なし |
| `serpens/ai-shared/HARDWARE_TODO.md` HT-005 / HT-011 | T6/T4 の道具。小基板の実寸は仮定（幅 12・高さ 3.2・長さ 18 [ASSUMED]） |
| HG-H2 の `tof_cliff.md`・`hardware_test_plan.md`（Engineering の worktree `agent/engineering-h1-j1`。未マージ・読み取り専用） | ToF 2 個は既定アドレスが同じ → **XSHUT で 1 個ずつ起動**。LED は高さ 6 mm 以下（Z9 で巡回検出 0.64）。判定は頭の XIAO。T6-1 は短距離モード・タイミング予算 20/33 ms |

## 3. GPIO 割り当て（**User 承認済み 2026-10-01**。ENTRY-K-0001 で Engineering に伝えた）

| XIAO ピン | GPIO | 使い道 | 備考 |
|---|---|---|---|
| D0 | GPIO1 | **XSHUT_L**（出力） | 起動順: 両方 L → 片方を上げてアドレス変更 → もう片方を上げる（ST: 既定アドレス 0x52（8 bit）= 0x29（7 bit）） |
| D1 | GPIO2 | **XSHUT_R**（出力） | |
| D2 | GPIO3 | **LED_L の PWM**（LEDC） | GPIO3 は**ストラッピング ピン**（JTAG 信号源の選択）。**内部プルなしで、外部が確定した値を与える必要がある**（ESP32-S3 DS v2.2 §3.4）。ゲートの 100 kΩ プルダウンで L に固定される。eFuse が既定（EFUSE_STRAP_JTAG_SEL = 0）なら GPIO3 は無視される（表 3-5）。**STRAP_JTAG_SEL = 1 にしている場合は GPIO3 = L で JTAG が GPIO39〜42 に切り替わる** |
| D3 | GPIO4 | **LED_R の PWM**（LEDC） | |
| D4 | GPIO5 | **SDA** | XIAO の I2C 既定ピン（Seeed wiki） |
| D5 | GPIO6 | **SCL** | 同上 |
| D6 / D7 | GPIO43 / 44 | 未使用（no-connect） | 予約: 胴の XIAO との UART（`tof_cliff.md` の「頭で判定 → UART で 1 ビット」） |
| D8 / D9 | GPIO7 / 8 | （DNP の 0 Ω リンク R15/R16）ToF の GPIO1 | **Sense の microSD（SCK / MISO）と共用**。既定は非接続 |
| D10 | GPIO9 | 未使用（no-connect） | microSD（MOSI）と共用 |
| 3V3 / GND | — | 電源 | |
| 5V | — | SJ1/SJ2 の 5V パッド（R3/R4 経由）**だけ**。既定では開放 | 上の「解釈の注意」 |

Sense のカメラは GPIO10〜18・38〜40・47・48、マイクは GPIO41/42 を使う（Seeed wiki）。上の割り当てと重ならない。

## 4. 電源と LED の電流（再計算: `python tools/led_budget.py`、出力は [led_budget_output.txt](led_budget_output.txt)）

### 4.1 入力と根拠

| 値 | 出典 | 確認 |
|---|---|---|
| NSSW157T: VF 2.8〜3.4 V（typ 3.1 V）@ IF = 80 mA、IF max 150 mA（Ta 74 °C まで）、θJA 95 °C/W、Φv 26 lm @ 80 mA、「nominal current の 10 % 以上で使うことを推奨」（nominal は 80 mA と**解釈**） | Nichia STS-DA1-1913 p.1–2, p.9, p.14 | ✅（解釈は 🔴） |
| VF(10 mA) ≒ 2.73 V | 同 p.11 の VF–IF グラフの**目視**（"参考値・保証なし" と明記） | 🔴 |
| Vcc: 3V3 = 3.2〜3.4 V、5V = 4.75〜5.25 V | 仮定（3V3 の精度は Seeed に記載なし）/ USB 2.0 の規定値 | 🔴 |
| MOSFET の Rds(on) 最大 0.075 Ω @VGS=2.5 V | Si2302CDS（Vishay S12-2336 Rev D）。AO3400A は最大 0.048 Ω（AOS Rev 3.1） | ✅ |
| VL53L1X: 測距中の平均 16 mA（最大 18）、ピーク 40 mA | ST DS12385 Rev 8 表 15 | ✅ |
| ESP32-S3: Wi-Fi 送信ピーク 340 mA（802.11b 1 Mbps @21 dBm、3.3 V、**チップのみ**）、GPIO の IOH 40 mA / IOL 28 mA、VOH 最小 0.8×VDD | Espressif ESP32-S3 Datasheet v2.2 表 5-7・表 5-4 | ✅ |
| XIAO ESP32S3 Sense: Webcam の平均 140 mA、撮影ピーク 347 mA（5V）/ 366 mA（3.8V バッテリー）、カメラ比較表の OV2640 MAX ≒ 0.65 A（**測定条件の記載なし**）、3V3 は「700 mA 引ける」（条件の記載なし） | Seeed wiki（Seeed の PDF データシートは見つからなかった） | 🟡 |

### 4.2 LED の電流（3V3 と 5V）

| 電源 | 抵抗 | 電流 最小 / 公称 / 最大（LED 1 個） | 抵抗の最大損失（定格比） | 80 mA 比（光量） |
|---|---|---|---|---|
| **3V3（既定）** | R1/R2 = **20 Ω 0603**（0.1 W） | 8.5 / 23.6 / 38.8 mA（絶対最大 150 mA の 6 / 16 / **26 %**） | 30 mW（**30 %**） | 11 / **30** / 49 % |
| **5V（SJ で選択）** | R3/R4 = **33 Ω 2010**（0.5 W） | 45.0 / 59.0 / 73.0 mA（同 30 / 39 / **49 %**） | 176 mW（**35 %**） | 56 / **74** / 91 % |

- 20 Ω は「最小電流が 80 mA の 10 % 以上」を保つ最大の E24 値（22 Ω 以上は 9.8 % 以下）。
- **5V 側の抵抗の選び方**（`led_budget.py`）: ① 最悪時の損失 ≦ 定格の 50 % ② 最大電流 ≦ 100 mA ③ 最小電流 ≧ 8 mA ④ LED の Tj ≦ 120 °C（Ta 50 °C 仮定）⑤ **5V の合計（LED 2 個の最大 + XIAO の撮影ピーク 347 mA）≦ USB 2.0 の 500 mA**。この基準で最小の E24 値は、**1206 なら 56 Ω**（28 / 37 / 46 mA、損失 119 mW = 48 %）、**2010 なら 33 Ω**。User の指示が「1206 以上」なので、明るい方の **2010 / 33 Ω** を採用した。1206 に 33 Ω を載せると 176 mW で定格の 70 % になり ① を満たさない。2010 / 24 Ω（96 %）は ⑤ を満たさない（5V 合計 536 mA）。
- **5V 用に 3V3 用の 20 Ω を使うと**最大 109 mA、0603 が 238 mW（定格の 238 %）で焼ける。SJ と R1/R3 は回路図のとおりに組む（SJ を切り替えれば抵抗も切り替わる構造）。
- LED の損失は最大 202 mW（定格 510 mW）、Tj ≒ 69 °C（Ta 50 °C、上限 120 °C）（5V 時）。

### 4.3 3V3 から取る電流の合計（Wi-Fi・カメラのピークを含む）

基板側（外部負荷）: LED（3V3、最大）77.6 + ToF ピーク 2×40 + XSHUT プルアップ 0.7 = **158 mA**（LED を 5V にすると **81 mA**）。XIAO 側は Seeed の値。3V3 が LDO なら 3V3 側の電流 ≒ 入力側（撮影ピークが 5V で 347 mA、3.8V で 366 mA とほぼ同じ = 入力電圧に依らない = LDO 的。**レギュレータの型番は Seeed に記載なし = 未確認**）。

| 想定（XIAO 自身） | XIAO 分 | 合計（LED=3V3） | 合計（LED=5V） | 出典・確認 |
|---|---|---|---|---|
| A. Webcam 平均 | 140 mA | 298 mA（43 %） | 221 mA（32 %） | Seeed wiki 🟡 |
| B. Webcam 撮影ピーク（バッテリー側の値） | 366 mA | **524 mA（75 %）** | 447 mA（64 %） | Seeed wiki 🟡 |
| C. カメラ比較表の MAX（OV2640 ≒ 0.65 A） | 650 mA | **808 mA（115 %）** | 731 mA（104 %） | Seeed wiki、**測定条件の記載なし = 未確認** |
| D. Wi-Fi 送信ピーク（チップ単体・参考） | 340 mA | 498 mA（71 %） | 421 mA（60 %） | Espressif ✅（カメラ・PSRAM・Flash は含まない） |

（% は Seeed の「3V3 で 700 mA」に対する割合。）
- **B までなら 524 mA で 700 mA 以内。C を上限と見ると 808 mA で超える**（LED を 5V にしても 731 mA）。C の条件は不明なので、**実機で XIAO の 5V 入力電流を測るまで、Wi-Fi 送信・撮影・LED 100 %・ToF ピークを同時にしない運用が安全側**。測定の依頼は ENTRY-K-0001（Engineering）。
- **5V 側**（LED を 5V にした場合）: LED 2 個の最大 146 mA + XIAO の撮影ピーク 347 mA = **493 mA（USB 2.0 の 500 mA 以内、余裕 7 mA）**。XIAO の 5V ピンの電流能力は Seeed に記載なし = **未確認**（5V を選ぶ前に確認）。

### 4.4 GPIO と MOSFET のゲート駆動

- GPIO は LED 電流を流さない（MOSFET のゲートのみ）。ゲート充電のピークは 3.3 V / 220 Ω = 15 mA（ns 単位）、XSHUT の L 出力は 0.33 mA。GPIO の IOH 40 mA / IOL 28 mA（ESP32-S3 DS v2.2 表 5-4）に対して十分小さい。
- **3.3 V ロジックで確実に駆動できる**: ESP32-S3 の VOH 最小 = 0.8 × VDD = 2.64 V（表 5-4）。
  - **AO3400A**（Alpha & Omega Rev 3.1、2023-07）: VGS(th) 0.65 / 1.05 / 1.45 V（最小/typ/最大）、RDS(on) < 48 mΩ @VGS=2.5 V・< 32 mΩ @4.5 V、VGS 最大 ±12 V、VDS 30 V、ID 5.7 A。2.64 V は VGS(th) 最大の 1.8 倍、RDS(on) の規定（2.5 V）以上 ✅
  - **Si2302CDS**（Vishay S12-2336 Rev D）: VGS(th) 0.40〜0.85 V、RDS(on) < 75 mΩ @2.5 V・< 57 mΩ @4.5 V、VGS 最大 ±8 V、VDS 20 V、ID 2.6 A。2.64 V は VGS(th) 最大の 3.1 倍 ✅
  - どちらも SOT-23、**1 = G、2 = S、3 = D**（Vishay は原本に明記。AOS の図は端子名のみで、番号は SOT-23 の標準配置）。LED 電流 最大 73 mA での Vds 降下は約 5 mV（0.075 Ω × 73 mA）。
- ゲート直列 220 Ω + 100 kΩ プルダウン: 起動中・リセット中は GPIO が浮くので LED を消しておく。

## 5. 部品表

→ **[bom.md](bom.md)**（型番・パッケージ・定格・DNP・備考。回路図から生成）と [bom.csv](bom.csv)。購入先・品番・価格の列は User が調べる。
（Stage 4 の注記: J1/J2 のフットプリントは、標準の上面シルク枠を除いた自作 `PinHeader_1x06_P2.54mm_NoSilk` に替えた。bom.md は Stage 2 のままなので、BOM を出力するときに再生成する。）
主な部品: XIAO ESP32S3 Sense ×1、NSSW157T ×2、AO3400A（または Si2302CDS）×2、R1/R2 20 Ω 0603、**R3/R4 33 Ω 2010**、R5/R6 220 Ω、R7/R8 100 kΩ、R9/R10 1 Ω 1 %、R11/R12 10 kΩ、R13/R14 3.3 kΩ（DNP）、R15/R16 0 Ω（DNP）、C1 10 µF 0805、C2/C3 100 nF 0603、1×6 ヘッダ ×2、1×2 ヘッダ ×2、半田ジャンパー ×2、TP ×8、M2 穴 ×2。基板の外: ピンソケット 1×7 ×2、ジャンパー線 ×12。

## 6. 外形・部品配置・配線（Stage 3 → Stage 4）

図: **[placement_routed.png](placement_routed.png)**（配線後の配置図）、[routing_layers.png](routing_layers.png)（表面・裏面を別々に）、KiCad の 3D ビュー [board_3d_iso.png](board_3d_iso.png)（斜め）・[board_3d_top.png](board_3d_top.png)（真上）・[board_3d_top_noxiao.png](board_3d_top_noxiao.png)（XIAO を外した状態）・[board_3d_bottom.png](board_3d_bottom.png)（裏面）。基板は `head-sensor-board.kicad_pcb`。
Stage 3 の配置図（40×25）は git の履歴（コミット 756b482）に残っている。

### 6.1 User の指示（Stage 4、2026-10-01）と結果

| 指示 | 結果 |
|---|---|
| 外形 **44×28 mm**（角 R1、M2 穴 ×2）。変数で作り直せるように | 44×28 mm、角 R1、M2 穴 ×2。**`python tools/make_board.py --width W --height H`** で外形・配置・配線をまとめて作り直せる（配線は自動なので、寸法を変えても DRC まで通す。右の縁・上下の縁に寄せた部品は縁についてくる） |
| L/R は今のまま。基板の刻印に「L」「R」と USB-C の向き | 上面の刻印: **「L」「R」**（1.5 mm、LED のすぐ下／上）、左下に**矢印（←）と「USB-C」**。J1/J2 には「J1 ToF-L」「J2 ToF-R」。裏面にも「L=LOWER / R=UPPER」。**2026-10-02: J1/J2 の信号名が樹脂部・パッドに重なっていたのを直した**（下の §6.2） |
| Seeed の XIAO ESP32S3 Sense の図面で、拡張ボード（カメラ・microSD）が XIAO の下へ張り出すか。配置と干渉するか | **§6.5**。拡張ボードは XIAO の**上面**に載り、下へは出ない。基板側の部品と干渉しない（カメラ・microSD の出っ張りは**未確認**）。ソケットの高さは**購入品で確認**（8.5 mm は仮定のまま） |
| 穴の位置はそのまま | 右の 2 つの角、縁から 2.1 mm のまま（頭への取り付けが決まったら見直す） |
| ToF のピン配置が未確認でもガーバー自体は出してよい（ジャンパー線）。**J1/J2 の 6 本の信号名（VIN, GND, SCL, SDA, XSHUT, GPIO1）を刻印** | 刻印した（ピンごとに 2 段の互い違い + 引き出し線。順は pin1 = VIN が右）。README に ToF 小基板のピン配置の欄と、J1/J2 ↔ 小基板のジャンパー線の対応表（現物が届いたら埋める）を足した。**2026-10-02: User が配線後の PNG を確認 → ガーバー・ドリル・位置ファイル・BOM・ZIP を `gerbers/` に出した（発注はしていない）** |
| 配線: 電源は太く、LED の電流の経路は 0.3 mm 以上、ToF の SDA/SCL は短く | §6.4 |
| DRC（エラー 0・未接続 0・回路図との不一致 0） | **達成**（§7） |
| KiCad の 3D ビュー、配線後の配置図 PNG | 上の 5 枚 |

### 6.2 配置の方針（Stage 3 からの変更点を含む）

- **向きの定義**: 上面から見て USB-C を左、LED の縁を右にする。**下半分 = L チャンネル**（XIAO の D0〜D6 の列に近い側）、**上半分 = R チャンネル**（L の鏡像）。**回路図の L/R は基板上の位置の名前で、ロボットの左右とは限らない**（ToF・LED はジャンパー線で自由に左右へ引けるので、取り付けのときに合わせる。合わなければ firmware のチャンネルを入れ替える）。
- **J1/J2（ToF ヘッダ）を 180° 回して pin1 を右にした。** XIAO の SDA（D4）が SCL（D5）の左にあるので、ヘッダも SDA が SCL の左になる向きにして、I2C の線が交差しないようにした（回路図の割り当て pin1 = VIN … pin6 = GPIO1 は変えていない。物理的な向きだけ）。ピンの x は XIAO のピン列と同じ 2.54 mm の格子に乗せた（pin1 = x 23.8 mm）。**標準フットプリントの上面シルク枠は、信号名の刻印と重なるので消した**（自作 `PinHeader_1x06_P2.54mm_NoSilk`。ランド・穴・コートヤードは標準のまま）。
- **J1/J2 の信号名の刻印（2026-10-02 に直した）**: ヘッダのピンの中心を縁から 1.45 mm（ランドの縁から 0.6 mm。Stage 4 の最初は 1.7 mm）に寄せ、**信号名は樹脂部（2.54 mm 角）の外**に 2 段で置いた（手前の段 = pin1・3・5、奥の段 = pin2・4・6。奥の段には樹脂部の手前までの引き出し線）。文字は大きさ 0.8 mm（線幅は 2026-10-05 に 0.12 → 0.15 mm に直した。発注先の最小値のため。§7）。最初の版は、手前の段の文字が樹脂部に 0.09〜0.17 mm 食い込み、引き出し線が樹脂部に触れていた（User の指摘のとおり）。**同じ検査で、SJ の「3V3」「5V」が R9/R10 のランドに近すぎた点、TP の名前が隣の TP のランドに近すぎた点も直した**（SJ の名前は SJ の枠の外の上下に、TP の名前はランドの内側へ）。
- **SJ1/SJ2 を縦並びにした**（pad1 = 3V3 側が中心線寄り、pad3 = 5V 側が縁寄り、pad2 は右の LED へ出る）。R1/R2 は pad1 の左、5V の 33 Ω（R3/R4）からの線は pad3 の左から入る。
- **R3/R4 を上下に分けた**（R4 = 上、R3 = 下）。Stage 3 は両方が上半分にあり、L チャンネルの 5V の線が上下をまたいでいた。
- **TP5（XSHUT_L）・TP6（XSHUT_R）を J1/J2 の右の縁へ移した**（TP5 = 下、TP6 = 上）。左下は USB-C の矢印の場所になった。TP1/TP3/TP4 は上の縁の左、TP2/TP7/TP8 は右のゾーン中央（電流は GND を基準に測るので GND を隣に置いた）。
- **XIAO の下（ソケットの内側）**に、小さい部品（0603 / 2010、C1 は 0805）を置いた（R3〜R8、R11〜R16、C1〜C3）。最も背が高いのは C1（0805 の 10 µF。一般値で 1.25 mm 以下。購入品で確認）。XIAO の外形ではなく**ピン列の帯だけ**をコートヤードにしてある。ソケットの高さは 8.5 mm と仮定（🔴）。**ピンヘッダ直付けにするときは、XIAO の底面とのすきま（約 2.5 mm）と C1 の高さを確かめる**。
- **上面に全部品**（SMD も THT も）。**裏面は部品なし**（GND ベタ + 配線の一部 + 凡例の刻印）。
- M2 穴は **LED の縁側の 2 つの角**。穴のコートヤードは標準の半径 2.4 mm（M2 なべ小ねじの頭を想定。🔴）。

### 6.3 高さと面積

- **高さの制限（6 mm 以下）は LED だけ**: NSSW157T = **0.52 mm ✅**（Nichia p.4）。ほかの部品には適用しない（User 指示）。
- **面積**: 44×28 = 1232 mm²。部品は余裕をもって収まり（コートヤードの重なり 0）、配線は表面 + 裏面の一部で済んだ。**もっと小さくするなら**、右のゾーン（LED・MOSFET・SJ）の寸法が主な制約。`tools/make_board.py --width 42 --height 26` などで DRC まで通るか試せる（試していない値は保証しない）。

### 6.4 配線（自動配線 `tools/route.py` + KiCad の DRC で検証）

- **方法**: 0.0635 mm の格子（XIAO のピン列の 2.54 mm = 40 マス。ピンのすきま 0.74 mm の中央に線が乗る）で、ネットごとに最短経路（scipy の Dijkstra）。すでに引いた銅・ランド・穴・基板の縁を障害物にし、クリアランス 0.2 mm、縁から 0.5 mm を守る。**太い幅を先に試し、通らなければ細くする。**通らないネットを先頭に移して全体をやり直す仕組みだが、今回は 1 回目で全ネットが通った。経路は 0°/45°/90°。
- **GND は配線せず、表面・裏面とも GND のベタ**（外形から 0.5 mm 内側まで、ランドへはサーマルリリーフ）。表面実装の GND ランド 8 か所（C1〜C3、R7〜R10、TP2）には、短い引き出し線 + ビア（0.6/0.3）を 1 つずつ打って、両面のベタにつないだ。スルーホールの GND ランド（U1、J1、J2）はそのままベタにつながる。
- **スルーホールのピン（XIAO の 14 本、J1/J2）は両面の銅なので、層の乗り換え（上下をまたぐ SDA / SCL / XSHUT_R など）にそのまま使った。** ビアは信号に 20 個、GND の引き出しに 8 個 = **28 個**。

| 種類 | 幅 | 長さの合計 | ネット |
|---|---|---|---|
| 電源 | **0.5 mm** | 80.9 mm | +3V3（77.1 mm）、+5V（3.7 mm） |
| LED の電流の経路 | **0.4 mm** | 111.5 mm | LEDA / LEDK / SENSE（L・R）、SJ の A（3V3 側）・B（5V 抵抗の先）、GND の引き出し線 |
| 信号 | 0.25 mm | 232.7 mm | SDA、SCL、XSHUT、PWM、GATE、GPIO1 の 0 Ω リンク（D8/D9）と ToF の INT |

（最小の幅 0.2 mm は使わずに済んだ。LED の電流は最大 73 mA。0.4 mm の線は、IPC-2221 の式（外層・温度上昇 10 °C・銅厚 35 µm と仮定）で約 1.2 A。銅厚は製造先の標準を仮定）

- **I2C の長さ**: SDA 32.2 mm、SCL 38.3 mm（XIAO → J1・J2・TP3/TP4・プルアップ R13/R14。J1 と J2 の間が約 25 mm あるため。ビアは 0 個）。400 kHz の I2C としては問題ない長さ。ToF 小基板までのジャンパー線の長さが支配的になる。
- **経路の確認方法**: DRC（クリアランス 0.2 mm、縁 0.5 mm、穴、ネットの短絡、未接続）。それ以外（信号の品質・EMC）は検証していない。

### 6.5 XIAO ESP32S3 Sense の拡張ボード（カメラ・microSD）が、基板側の部品に干渉するか（User 指示 3）

確認した資料: Seeed の XIAO ESP32S3 Sense の**表面・裏面のピン配置図**（wiki の画像）、Seeed 提供の**拡張ボードの DXF 図面**、wiki の寸法（Sense 全体 21 × 17.8 × 15 mm）。

| 項目 | 分かったこと | 確認 |
|---|---|---|
| どの面に載るか | 拡張ボードは XIAO の**上面**（USB-C と同じ面）の、**USB-C と反対側の端**に、B2B コネクタ（30 ピン）で載る。つまりこの基板の**上向き**で、基板側（下）へは出ない | 🟡（図の目視） |
| XIAO の下面 | **平らなパッドだけ**（BAT+/−、MTDO/MTDI/EN/MTCK/MTMS、USB D±）。背の高い部品はない → ソケットの内側の空間は、基板側の小さい部品（最大 約 1.25 mm）と干渉しない | 🟡 |
| 拡張ボードの外形 | DXF の外形 **17.83 × 15.42 mm**（角は面取り）。XIAO（21 × 17.8）の中に収まる（幅だけ XIAO の 17.8 より 0.03 mm 大きいが、図面の丸めの範囲）。**平面で XIAO の外形の外へは出ない** → J1/J2・TP・SJ・LED など、XIAO の外形の外にある部品の真上にはならない | ✅（DXF） |
| 干渉の結論 | **基板側の部品との干渉はない**。XIAO の外形の外にある J1/J2 は、ピンの中心が XIAO の縁から 3.65 mm 外にあり、立てたジャンパー線のコネクタ（幅 約 2.5 mm は一般値）の縁まで約 2.4 mm あく | 🟡 |
| **未確認** | カメラモジュール（FPC つき）と microSD カードの**出っ張り**（カードを差した状態の飛び出し量・向き）、拡張ボードの厚さ、B2B の高さ。Seeed の wiki は全体を 21 × 17.8 × 15 mm としているので、カメラ・カードも XIAO の枠内に収まるはずだが、**これは wiki の記載であって図面での確認ではない** | 🔴 |

- **現物が届いたら確認すること**: ① カメラの向き・FPC の通り道と、頭の中の他の部品 ② microSD カードの抜き差しの向き（カードが XIAO の USB-C と反対の端から出るなら、右の端（x = 21.6 mm より右）の上に出る）③ ソケットの実際の高さ（8.5 mm は仮定）。
- 3D ビューの XIAO・拡張ボードは `tools/gen_3d.py` の**簡易モデル（箱）**で、寸法の根拠にしない（カメラ・microSD は作っていない、拡張ボードの高さは仮）。

### 6.6 まだ決まっていない・試していない点

- 頭の中での基板の向き・取り付け（M2 穴は仮）。
- 実機での動作（LED の明るさ、ToF の読み、I2C のアドレス変更）はもちろん未検証。

## 7. 検証（Stage 2〜4 と製造データ）

| 検査 | 結果 | 置き場所 |
|---|---|---|
| **DRC（回路図との対応つき、`--severity-all`）** | **違反 0 件、未接続 0、フットプリント・回路図の不一致 0**（2026-10-02、製造データを出す直前）。クリアランス 0.2 mm・縁 0.5 mm・穴・刻印・コートヤード・ネットの短絡を含む。**プロジェクトの設定で「無視」だった 4 種（コートヤード未定義・フットプリントの種類の不一致・フィルタ不一致・ビアの中心のずれ）も「エラー」に直して 0 件** | [drc_report.txt](drc_report.txt) |
| **J1/J2 の突き合わせ**（基板を直接読む） | 12 パッドすべてで、**基板のネット = 回路図（KiCad が出したネットリスト）のネット = 刻印の名前**。四角いパッドは pin1 だけ（右端）。刻印の並び（左から）: GPIO1 XSHUT SDA SCL GND VIN | `python tools/check_board.py` |
| **刻印のすきま** | 上面の刻印 137 個が、ランド・ヘッダの樹脂部・ほかの刻印・XIAO の外形・基板の縁と 0.1 mm 以上あいている（最初の版は 21 件の問題があった。直して 0 件） | 同上 |
| ERC（プロジェクトの設定どおり / 無視される 4 種を有効にした厳格版） | **エラー 0 / 0 件** | [erc_report.txt](erc_report.txt)、[erc_report_strict.txt](erc_report_strict.txt) |
| ネットリストの照合（期待 25 ネットと KiCad の出力の突き合わせ）、フットプリントのパッド番号の照合 | **25/25 一致**、40 部品すべてで回路図のピンがパッドに存在 | `python tools/check_netlist.py` |
| **ガーバー・ドリルの読み直し**（KiCad とは別の gerbonara で、ZIP の中身だけを読む） | 層は 8 層（表裏の銅・レジスト・シルク、表ペースト、外形）+ ドリル PTH / NPTH。**外形 44.000 × 28.000 mm、原点は左下**。銅は縁から 0.500 mm 以上。**ドリル 60 個**（PTH 58 = 0.3 mm のビア 28 + 1.0 mm の J1〜J4 16 + 1.02 mm の XIAO 14、NPTH 2 = M2 穴 φ2.2）が、基板のスルーホールのランドと routes.json のビアの位置・径に **1 対 1 で一致**。全ランド・全トラックの端・全ビアに銅の図形がある（抜け 0） | `python tools/verify_gerbers.py` |
| 半田ジャンパーのネットタイ（1-2 を銅で橋渡し） | 標準フットプリントに `net_tie_pad_groups "1,2"` あり ✅。配線後の DRC でも短絡にならない | KiCad 標準ライブラリ |
| 配線の再現性 | `python tools/make_board.py` で外形・配置・配線・ベタ・DRC まで一括で作り直せる | `tools/` |
| **発注先 4 社の公開仕様との照合**（JLCPCB・PCBWay・Seeed Fusion・Elecrow。2026-10-05 に公開ページから取った値） | 配線幅・間隔・ビア・穴・アニュラリング・銅と縁・ランドどうしのすきま・板厚・外形は**全社 PASS**（Elecrow の配線間隔は最小 6 mil を満たし、推奨の 8 mil 超には 0.2 mm = 7.9 mil で届かず WARN）。**シルクの線幅は 0.12 → 0.15 mm に直して全社 PASS**。**文字の高さ 0.8 mm は JLCPCB の標準（1.0 mm 以上）だけ未達**で、「高精度の文字」オプション（0.8 mm 以上）なら通る | [fab_check.md](fab_check.md)、`tools/check_fab_rules.py` |
| **ガーバーが最新か**（今の基板から作り直した図形と、gerbers/ の図形を、順序に関係なく比較） | 全層で同じ図形（銅・レジスト・ペースト・外形・ドリル 60 個・シルク）。シルク修正の前後の比較では、**銅・レジスト・ペースト・外形・ドリルは図形として完全に同一で、シルクの線の太さだけが違った** | `python tools/compare_gerbers.py --current` / `HEAD gerbers/…zip` |
| **全検査の一括実行** | ERC・DRC・ネットリスト・J1/J2 と刻印・発注先 4 社・ガーバーの最新性・ZIP の読み直しがすべて通る（発注先は JLCPCB の標準の文字高さだけ PASS*） | `python tools/run_all_checks.py` |
| 回路図の PDF | 出力した | [head-sensor-board_schematic.pdf](head-sensor-board_schematic.pdf) |

**製造データ**: `gerbers/`（[README](../gerbers/README.md)）。ZIP は `gerbers/head-sensor-board_gerbers.zip`（11 ファイル）。BOM は `docs/bom.md`（読みやすい版）と `gerbers/head-sensor-board_BOM.csv`、位置ファイルは表面実装で実装するものだけ。**発注はしていない**。
回路図は `tools/gen_schematic.py` で生成したもの（KiCad で手直しした後に再生成すると手直しが消える）。

## 8. 未確認・仮定の一覧

1. **ToF 小基板のピン配置**、基板上のプルアップ・LDO・レベルシフタの有無、I2C アドレス、実寸 — 販売ページ（Amazon B083Z316NC）に記載なし。**ヘッダの並び（1 VIN, 2 GND, 3 SCL, 4 SDA, 5 XSHUT, 6 GPIO1）は仮。** ジャンパー線で接続するので、並びが違っても基板の作り直しは不要（線でつなぎ替える）。README に、小基板のピン配置の欄と対応表を用意した（現物が届いたら埋める）。
2. NSSW157T の入数（販売ページは ¥200/パック）。
3. XIAO の 3V3 の精度・レギュレータ型番、「700 mA」の条件、カメラ表 MAX 0.65 A の条件、**5V ピンの電流能力**。
4. MOSFET の購入品の型番（AO3400A / Si2302CDS はどちらも原本で確認したが、購入品は未定）。
5. VF(10 mA) はグラフの目視。ユニット差 ±0.3 V は「2.8〜3.4 V」を typ から対称に見た近似。Vcc の幅も仮定。
6. 「nominal current の 10 %」の nominal = 80 mA という解釈。
7. **ソケット・ヘッダの高さ（8.5 mm は仮定）**。XIAO の下に置いた部品（最大 C1 約 1.25 mm）が、購入するソケット・ヘッダで XIAO の底面に当たらないか（ソケット 8.5 mm なら十分。ピンヘッダ直付けなら隙間 約 2.5 mm）。
8. Seeed の 15.25 mm は「XIAO シリーズ共通の図面」で、ESP32S3 個別の図面ではない。
9. **BoardRepo での表示**（User が手動でアップロードする。表示できたかは User の確認が要る）。
10. 頭の内部の配置（基板を頭のどこに、どの向きで取り付けるか）は未定。M2 穴は LED の縁側の 2 つの角（頭への取り付け方法が分かったら見直す）。M2 の頭の大きさ（穴のコートヤード半径 2.4 mm）は想定。
11. USB-C ケーブルの差し込み（XIAO の USB-C 端が基板の縁から 0.6 mm 内側）の実物での確認は未実施。
12. 基板上の L/R（下半分 = L）はロボットの左右とは限らない（§6.2）。
13. **XIAO Sense のカメラ・microSD の出っ張り、拡張ボードの厚さ・高さ**（§6.5。Seeed の wiki の全体寸法 21 × 17.8 × 15 mm を信じるなら XIAO の枠内）。
14. 3D モデル（XIAO・拡張ボード・LED）は簡易な箱。**見た目の確認用**で、寸法の根拠にしない。
15. **配線の電気的な検証**（I2C の波形、LED の電流、電源のノイズ）は未実施。DRC は幾何学的な検査だけ。
16. **発注先の仕様との照合は、公開ページの値との机上の照合だけ**（`docs/fab_check.md`。注文して確かめたものではない）。**JLCPCB の標準の文字は高さ 1.0 mm 以上が必要で、この基板は 0.8 mm（線幅 0.15 mm）。JLCPCB なら「高精度の文字」を選ぶ（追加費用の有無は未確認）。** 高さを 1.0 mm にするには J1/J2 の信号名の 2 段が入る帯が足りず、基板の高さを 28 → 29 mm 程度にする案（計算上。実際に配置・配線して確かめていない）。銅厚・表面処理は基板データに指定がない（`gerbers/README.md`）。
17. **ガーバーを製造所のビューアで見ていない**（gerbonara による読み直しと KiCad の DRC だけ）。発注前に、発注先のオンライン確認で外形・穴・シルクを目で見ること。

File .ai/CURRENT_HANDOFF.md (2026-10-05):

# Current Handoff — head-sensor-board (KiCad Agent)

更新: 2026-10-05。次のセッションは、この 1 枚と `PROJECT_STATE.json` / `TASK_GRAPH.json` / `*.jsonl` から、過去の会話なしで再開できる。
ルール: **発注しない**（人の操作）。**測定値を作り話で埋めない**。`ai-shared/` と `ai-outbox/` は追記専用。他の Agent の worktree に触れない。

## Completed

- Stage 1〜4（仕様、回路図 ERC 0、外形 44×28 mm と配置、配線、DRC 0、3D ビュー）。
- 製造データ `gerbers/`（ガーバー 8 層 + ドリル + pos + BOM + ZIP）。2026-10-02 に出力、2026-10-05 にシルクを修正して再出力（commit 63e2481）。
- 2026-10-05 の閉ループ（EXP-K-0001）: 発注先 4 社の公開仕様（JLCPCB・PCBWay・Seeed Fusion・Elecrow）を取得 → **シルクの線幅 0.12 mm が JLCPCB 標準・PCBWay・Elecrow の最小 0.15 mm 未満**と判明 → 全シルク 0.15 mm に修正 → **銅・レジスト・ペースト・外形・ドリルは図形として同一、シルクだけが違う**ことを確認 → KEEP。
- 自動化: `tools/run_all_checks.py`（全検査）、`check_fab_rules.py` + `fab_rules.json`（発注先との照合）、`compare_gerbers.py`（図形比較。`--current` で gerbers/ が古くなっていないか）、`check_board.py`（J1/J2 のネット・パッド・刻印、刻印のすきま 0.15 mm）、`gen_bringup_tables.py`。
- 人の作業の手順書 `docs/bringup_plan.md`（HG-K-01〜09、期待値は設計の計算値）+ `docs/bringup_nets.md`。

## Current State（検証の梯子。`PROJECT_STATE.json`）

| 対象 | 状態 |
|---|---|
| 回路図・基板の幾何（DRC / ERC / ネットリスト / J1・J2 / 刻印） | SOFTWARE_VERIFIED |
| 配置図 PNG | HUMAN_INSPECTED（2026-10-02 の PNG。その後のシルクの微修正は User 未確認） |
| ガーバー | SOFTWARE_VERIFIED（別ライブラリで読み直し）。User 未確認、製造所のビューア未確認 |
| 発注先との適合 | SOFTWARE_VERIFIED（公開仕様との机上照合。**注文して確かめていない**）。JLCPCB の標準の文字高さ 1.0 mm だけ未達（高精度の文字オプションなら可） |
| 3D モデル | IMPLEMENTED（簡易な箱、高さは仮） |
| 実機 | **なし（HARDWARE_VERIFIED = 0）。未発注** |

## Evidence

`EVIDENCE.jsonl`（EV-K-0001〜0013）。主なもの: gerbonara による ZIP の読み直し（EV-K-0003）、シルク修正の前後の図形比較（EV-K-0009）、発注先の仕様（EV-K-0005/0006。URL と取得日つき）、`run_all_checks.py` の結果（EV-K-0011）。

## Experiments

- EXP-K-0001 シルクの線幅 → **KEEP**（commit 63e2481）。
- EXP-K-0002 基板の高さ 29 mm + 文字 1.0 mm（JLCPCB の標準のシルク）→ **NOT_RUN**（承認済みの 44×28 を変える。JLCPCB の高精度オプションが使えないときだけ）。

## Decisions

DEC-K-0001〜0005（`DECISIONS.jsonl`）。**DEC-K-0004 が OPEN（User）**: JLCPCB で発注するなら「高精度の文字」を選ぶ（費用は未確認）か、高さ 29 mm + 文字 1.0 mm を承認するか。ほかの 3 社は現状のままで通る。

## Failed Attempts / 自分の誤り

- 最初の J1/J2 の信号名はヘッダの樹脂部に食い込んでいた（DRC は樹脂部を知らない）→ `check_board.py` を作った。
- シルクの線幅 0.12 mm が発注先の最小に届いていなかった（発注先との照合を最後まで先送りしていた）→ 照合を自動化した。
- ガーバーを文字列で比べると、同じ図形でも「違う」と出る（KiCad が出力のたびに順序を変える）→ 図形比較にした。
- スクリプトに `\n` を含む文字列をシェルから流し込むと化ける問題が再発（ファイル編集ツールか `chr(10)` を使う）。

## Open Questions

1. DEC-K-0004（上）。 2. ToF 小基板のピン配置（README の対応表。現物が要る）。 3. M2 穴の位置（頭への取り付け未定）。 4. ソケットの高さ・カメラ/microSD の出っ張り（HG-K-08）。 5. BoardRepo の表示（User が zip を手動アップロード。未確認）。

## Human Gates

`docs/bringup_plan.md` の HG-K-01〜09（目的・必要な物・手順・測定項目・期待値・失敗時・証拠・合格基準・安全・所要時間）。要約は `serpens/ai-outbox/human-actions/HUMAN-ACTIONS-KICAD-2026-10-05.md`。**HG-K-01（発注の前の確認）が最初**。

## Next Best Tasks

1. （人）HG-K-01: 発注先を決め、プレビューでシルク・外形・穴を確認、発注。DEC-K-0004 を決める。
2. （Agent）発注先が JLCPCB で高精度オプションが使えないとき: EXP-K-0002 を実行（`gen_pcb.py` の文字の大きさと GLYPH 定数を 1.0 mm で測り直し、高さ 29 mm、再配線、`run_all_checks.py`）。
3. （人）基板・小基板・XIAO Sense が届いたら HG-K-02〜09。測定値を `docs/bringup_log_YYYYMMDD.csv` に返す → Agent が spec/README を更新し、必要なら Rev B。
4. 基板を直したら必ず: `tools/check_board.py` → `tools/make_fabrication.py` → `tools/run_all_checks.py`。

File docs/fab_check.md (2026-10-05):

# 発注先の公開仕様との照合（`tools/check_fab_rules.py` が作る。手で直さない）

公開仕様の取得日 2026-10-05。**公開ページの値との机上の照合であって、注文して確かめたものではない。** 発注の前に、発注ページの最新の値と照合すること。値は mm。括弧 = 発注先の最小（推奨）。

| 項目 | 基板 | JLCPCB | PCBWay | Seeed Fusion | Elecrow |
|---|---|---|---|---|---|
| 配線の最小幅 | 0.250 | PASS (0.1) | PASS (0.1) | PASS (0.1016) | PASS (0.1524) |
| 配線の間隔 | 0.200 | PASS (0.1) | PASS (0.1) | PASS (0.1016) | WARN (0.1524) |
| ビアの穴径 | 0.300 | PASS (0.15) | PASS (0.15) | PASS (0.2) | PASS (0.3) |
| ビアの外径 | 0.600 | PASS (0.25) | - | - | - |
| 最小の穴径（ビア・スルーホール） | 0.300 | PASS (0.15) | PASS (0.15) | PASS (0.2) | PASS (0.3) |
| 部品のスルーホールのアニュラリング | 0.350 | PASS (0.2) | PASS (0.15) | - | - |
| シルクの線の太さ | 0.150 | PASS (0.15) | PASS (0.15) | PASS (0.1016) | PASS (0.15) |
| シルクの文字の高さ | 0.800 | FAIL* (1) | PASS (0.8) | PASS (0.5842) | PASS (0.8) |
| 基板上の刻印とランドのすきま | 0.197 | PASS (0.15) | - | - | - |
| ランドどうしのすきま（マスクのブリッジ） | 0.250 | PASS (0.1) | PASS (0.1) | PASS (0.1) | - |
| 銅と縁の距離 | 0.500 | PASS (0.2) | PASS (0.25) | PASS (0.3) | - |

- `FAIL*` = 上位オプション（JLCPCB の「高精度の文字」: 線幅 0.10 以上・高さ 0.8 以上）なら通る。`WARN` = 最小は満たすが推奨値に届かない。`-` = 仕様に記載なし。
- 基板の値の出し方: 配線・ビア・穴・シルクの太さと文字の高さは基板から直接。間隔と銅と縁はプロジェクトの規則（DRC が守る値）。ランドとのすきまは基板上の刻印について。ランドどうしのすきま 0.25 mm は半田ジャンパーの 3 パッドの間（わざとはんだでつなぐ）。
- 部品の標準の枠（ライブラリのシルク）には、ランドに触れるものがある（最小 −0.075 mm）。ガーバーは `--subtract-soldermask` で、ランドの上のシルクを除いてある。JLCPCB は 0.15 mm 以内の文字を消すので、その部分の枠は欠ける（機能には影響しない）。

## 板厚・外形

- JLCPCB: 板厚 1.6 mm PASS、外形の大きさ PASS
- PCBWay: 板厚 1.6 mm PASS、外形の大きさ PASS
- Seeed Fusion: 板厚 1.6 mm PASS、外形の大きさ PASS
- Elecrow: 板厚 1.6 mm PASS、外形の大きさ PASS

## 出典（2026-10-05 取得）

- JLCPCB: https://jlcpcb.com/capabilities/pcb-capabilities、https://jlcpcb.com/blog/character-design-specifications
  - 注: 標準の文字は線幅 0.15 / 高さ 1.0 以上。注文画面の「高精度の文字」を選ぶと 0.10 / 0.8 まで（追加費用の有無は未確認）。ランドから 0.15 mm 以内の文字は消される。PTH のアニュラリング 0.20 以上（推奨 0.25）がビアにも当たるかは資料からは不明
- PCBWay: https://www.pcbway.com/capabilities.html
  - 注: ソルダーマスクのブリッジ 4 mil（緑）
- Seeed Fusion: https://wiki.seeedstudio.com/ja/Service_for_Fusion_PCB/
  - 注: 1 oz の最小パターン幅/間隔 4/4 mil。ソルダーマスクダム: 緑 0.10、その他 0.13 mm 以上
- Elecrow: https://www.elecrow.com/pcb-manufacturing.html
  - 注: 最小 6 mil（推奨は 8 mil より大きく）。最小パッド間隔 8 mil。ドリル最小 0.3 mm。銅と縁の距離・マスクのブリッジは資料に記載なし

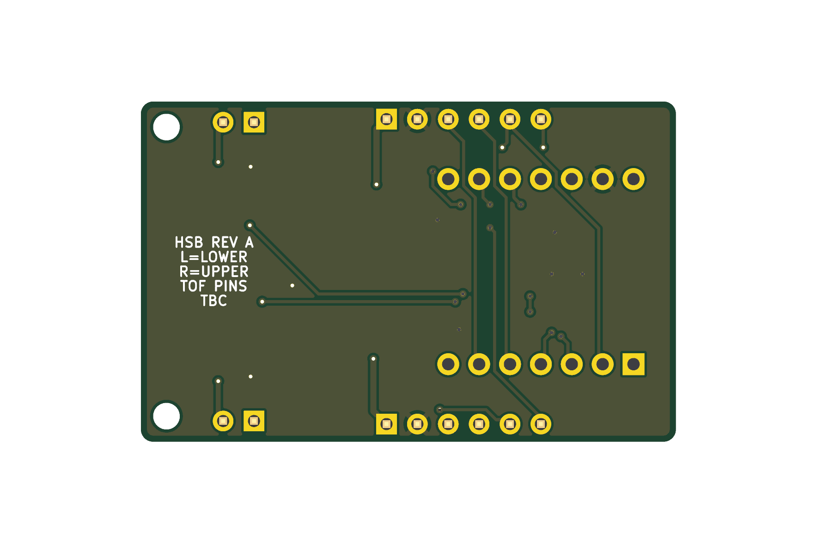
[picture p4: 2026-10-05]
docs/board_3d_bottom.png

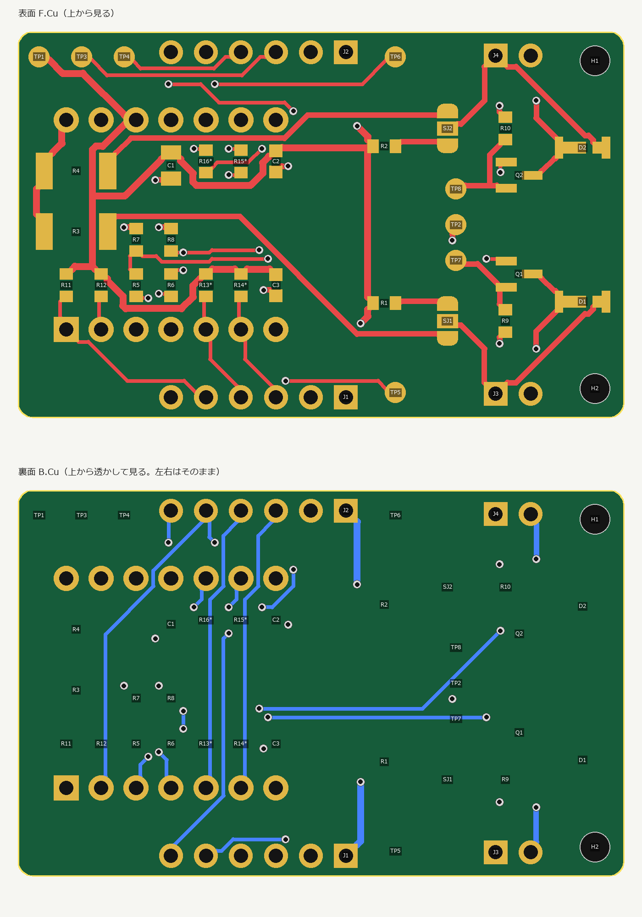
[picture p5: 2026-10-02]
docs/routing_layers.png

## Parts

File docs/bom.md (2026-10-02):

# BOM（部品表）— head-sensor-board Rev A（製造データ出力時）

**回路図から `tools/make_outputs.py` が作る。手で直さない**（直すときは回路図 → 再生成）。生の書き出しは [bom.csv](bom.csv)。
DNP = 既定で実装しない（フットプリントだけ置く）。**購入先・品番・価格の列は、User が秋月などで調べて埋める**（ここでは仕様だけ）。
抵抗・コンデンサは汎用品（型番の指定なし）。**仕様（値・パッケージ・定格）を満たせばよい。** 許容差: R9/R10（電流検出 1 Ω）は ±1 %、ほかの抵抗は ±5 % 以内、R15/R16 は 0 Ω ジャンパー。コンデンサは C1 が X5R 以上・10 V 以上、C2/C3 が X7R・16 V 以上。

## 1. 基板に載せる部品（回路図から）

| 記号 | 数量 | 値 | パッケージ（フットプリント） | 型番・種類 | 定格 | DNP | 備考 | 購入先・品番・価格 |
|---|---|---|---|---|---|---|---|---|
| U1 | 1 | XIAO_ESP32S3_Sense | `head-sensor-board:XIAO_ESP32S3_THT_2x7_P2.54mm` | Seeed XIAO ESP32S3 Sense | 3V3 out 700 mA (Seeed wiki, condition not stated) |  | Akizuki 118079. Mount on 2x 1x7 sockets (or pin headers). USB-C side = up in the drawing | （User が調査） |
| J1, J2 | 2 | ToF_L (PLACEHOLDER) / ToF_R (PLACEHOLDER) | `head-sensor-board:PinHeader_1x06_P2.54mm_NoSilk` | PinHeader 1x06 2.54 mm | 2.54 mm pitch |  | VL53L1X small module (Amazon B083Z316NC) on jumper wires. PIN ORDER IS A PLACEHOLDER - UNVERIFIED (module not in hand) | （User が調査） |
| J3, J4 | 2 | LED_L_EXT (1:+ 2:-) / LED_R_EXT (1:+ 2:-) | `Connector_PinHeader_2.54mm:PinHeader_1x02_P2.54mm_Vertical` | PinHeader 1x02 2.54 mm | current-limited node (after R1/R3) |  | External LED: pin 1 = + (LEDA, after the series resistor), pin 2 = - (LEDK). Do NOT short + to - | （User が調査） |
| SJ1, SJ2 | 2 | LED_L_SUPPLY / LED_R_SUPPLY | `Jumper:SolderJumper-3_P1.3mm_Bridged12_RoundedPad1.0x1.5mm` | solder jumper (PCB pads) | - |  | Default: pads 1-2 bridged = 3V3 via R1/R2. For 5V: cut the 1-2 bridge, bridge 2-3 (via R3/R4) | （User が調査） |
| D1,D2 | 2 | NSSW157T | `head-sensor-board:LED_Nichia_NSSW157T` | NSSW157T（Nichia） | IF 150 mA max; VF 2.8-3.4 V @80 mA; 3.0x1.4x0.52 mm |  | Akizuki 116884. White chip LED, height 0.52 mm | （User が調査） |
| Q1,Q2 | 2 | AO3400A | `Package_TO_SOT_SMD:SOT-23` | AO3400A (alt. Si2302CDS)（Alpha & Omega (alt. Vishay)） | 30 V 5.7 A VGS(th) 0.65-1.45 V RDS(on)<48 mohm @2.5 V (alt. Si2302CDS 20 V 2.6 A 0.40-0.85 V <75 mohm) |  | SOT-23 pin 1=G 2=S 3=D. Gate driven by 3.3 V logic | （User が調査） |
| R1,R2 | 2 | 20 | `Resistor_SMD:R_0603_1608Metric` | chip resistor 20 ohm | 0.1 W (0603) |  | LED current limit @3V3 (20 ohm: 8.5/23.6/38.8 mA min/nom/max) | （User が調査） |
| R3,R4 | 2 | 33 | `Resistor_SMD:R_2010_5025Metric` | chip resistor 33 ohm | 0.5 W (2010) |  | LED current limit @5V (33 ohm 2010: 45/59/73 mA min/nom/max). Fitted, used only when SJ is set to 5V | （User が調査） |
| R5,R6 | 2 | 220 | `Resistor_SMD:R_0603_1608Metric` | chip resistor 220 ohm | 0.1 W (0603) |  | Gate series resistor (limits the gate charge peak to 15 mA) | （User が調査） |
| R7,R8 | 2 | 100k | `Resistor_SMD:R_0603_1608Metric` | chip resistor 100k ohm | 0.1 W (0603) |  | Gate pull-down: LED off during reset/boot (GPIO3 is a strapping pin) | （User が調査） |
| R9,R10 | 2 | 1 | `Resistor_SMD:R_0603_1608Metric` | chip resistor 1 ohm | 0.1 W (0603) 1 % |  | Current sense: TP ILED voltage = 1 mV per mA (1 %) | （User が調査） |
| R11, R12 | 2 | 10k | `Resistor_SMD:R_0603_1608Metric` | chip resistor 10k ohm | 0.1 W (0603) |  | XSHUT pull-up (ST DS12385 2.4: XSHUT must always be driven; 10k recommended) / XSHUT pull-up (ST DS12385 2.4) | （User が調査） |
| R13, R14 | 2 | 3.3k | `Resistor_SMD:R_0603_1608Metric` | chip resistor 3.3k ohm | 0.1 W (0603) | **DNP** | I2C pull-up. DNP: fit only if the module has none (ST Table 4: 3.6k for CL<=90 pF) / I2C pull-up. DNP: fit only if the module has none | （User が調査） |
| R15,R16 | 2 | 0 | `Resistor_SMD:R_0603_1608Metric` | chip resistor 0 ohm | 0 ohm jumper | **DNP** | GPIO1 link to XIAO D8/D9 (shares the Sense microSD SPI pins). Default: not fitted | （User が調査） |
| C1 | 1 | 10u | `Capacitor_SMD:C_0805_2012Metric` | ceramic capacitor 10uF | 10 V X5R 0805 |  | 3V3 bulk: LED PWM + ToF peaks (2 x 40 mA) | （User が調査） |
| C2, C3 | 2 | 100n | `Capacitor_SMD:C_0603_1608Metric` | ceramic capacitor 100nF | 16 V X7R 0603 |  | Bypass near ToF header J1 / Bypass near ToF header J2 | （User が調査） |

回路図に出るが部品ではないもの: **TP1〜TP8**（テストポイントのパッド φ1.5 mm、自作 `TestPoint_Pad_D1.5mm_NoSilk`。部品なし）、**H1, H2**（M2 取付穴 φ2.2、`MountingHole:MountingHole_2.2mm_M2`）、**SJ1, SJ2**（半田ジャンパーのパッド。部品なし）。

## 2. 基板の外の部品（組み立てに必要）

| 用途 | 数量 | 品名 | パッケージ・寸法 | 定格・メモ | DNP | 備考 |
|---|---|---|---|---|---|---|
| U1 用 | 2 | ピンソケット 1×7（メス） | 2.54 mm ピッチ、スルーホール | 高さ 8.5 mm と仮定（購入品で確認） | — | XIAO を載せる。ピンヘッダ（オス）に替えてもよい（同じパッド） |
| XIAO 側 | 2 | ピンヘッダ 1×7（オス） | 2.54 mm ピッチ | Seeed の 7 pin ヘッダ SKU 320020159 は全長 10.34 / 上 6.00 / 下 1.80 mm | — | XIAO に同梱かは**未確認**。無ければ購入 |
| J1, J2 用 | 12 | ジャンパー線（ToF 小基板との接続） | ToF 小基板のピンの種類による（メス–メス / メス–オス） | — | — | ToF のピン配置・コネクタは**未確認**。候補: 秋月 100288「ブレッドボード・ジャンパーワイヤ 14 種類×10 本」（`秋月_購入リスト_20260930.md` に記載。**xlsx の購入リストには無い**） |
| H1, H2 用 | 2 | M2 ねじ（+ スペーサ） | M2、取付穴 φ2.2 | — | — | 頭への取り付け方法が未定のため**未決**（任意） |

## 3. 仕様の根拠（主なもの）

- **NSSW157T**: Nichia STS-DA1-1913（秋月配布）— IF max 150 mA、VF 2.8〜3.4 V @80 mA、3.0×1.4×0.52 mm。
- **AO3400A**: Alpha & Omega Rev 3.1（2023-07）— 30 V / 5.7 A、VGS(th) 0.65〜1.45 V、RDS(on) < 48 mΩ @VGS=2.5 V、VGS 最大 ±12 V、SOT-23。**Si2302CDS**（Vishay S12-2336 Rev D）— 20 V / 2.6 A、VGS(th) 0.40〜0.85 V、RDS(on) < 75 mΩ @2.5 V、VGS 最大 ±8 V、SOT-23（1=G, 2=S, 3=D）。どちらも 3.3 V ロジックで駆動できる（ESP32-S3 の VOH 最小 2.64 V でも VGS(th) 最大の 1.8 倍以上）。
- **R3/R4（5V 用 33 Ω 2010）**: 最悪時 176 mW = 0.5 W の 35 %（`tools/led_budget.py`）。0603/0805 では足りない（1206 でも 70 % で 50 % 基準を超える）。
- **R1/R2（3V3 用 20 Ω 0603）**: 最悪時 30 mW = 0.1 W の 30 %。
- **C1（10 µF）**: 3V3 電源だめ。X5R の 10 µF は DC バイアスで容量が下がるので、10 V 以上を選ぶ。

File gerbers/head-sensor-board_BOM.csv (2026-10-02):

Refs | Value | Footprint | MPN | Manufacturer | Rating | Notes | Qty | DNP
C1 | 10u | Capacitor_SMD:C_0805_2012Metric | ceramic capacitor 10uF |  | 10 V X5R 0805 | 3V3 bulk: LED PWM + ToF peaks (2 x 40 mA) | 1
C2 | 100n | Capacitor_SMD:C_0603_1608Metric | ceramic capacitor 100nF |  | 16 V X7R 0603 | Bypass near ToF header J1 | 1
C3 | 100n | Capacitor_SMD:C_0603_1608Metric | ceramic capacitor 100nF |  | 16 V X7R 0603 | Bypass near ToF header J2 | 1
D1,D2 | NSSW157T | head-sensor-board:LED_Nichia_NSSW157T | NSSW157T | Nichia | IF 150 mA max; VF 2.8-3.4 V @80 mA; 3.0x1.4x0.52 mm | Akizuki 116884. White chip LED, height 0.52 mm | 2
J1 | ToF_L (PLACEHOLDER) | head-sensor-board:PinHeader_1x06_P2.54mm_NoSilk | PinHeader 1x06 2.54 mm |  | 2.54 mm pitch | VL53L1X small module (Amazon B083Z316NC) on jumper wires. PIN ORDER IS A PLACEHOLDER - UNVERIFIED (module not in hand) | 1
J2 | ToF_R (PLACEHOLDER) | head-sensor-board:PinHeader_1x06_P2.54mm_NoSilk | PinHeader 1x06 2.54 mm |  | 2.54 mm pitch | VL53L1X small module (Amazon B083Z316NC) on jumper wires. PIN ORDER IS A PLACEHOLDER - UNVERIFIED (module not in hand) | 1
J3 | LED_L_EXT (1:+ 2:-) | Connector_PinHeader_2.54mm:PinHeader_1x02_P2.54mm_Vertical | PinHeader 1x02 2.54 mm |  | current-limited node (after R1/R3) | External LED: pin 1 = + (LEDA, after the series resistor), pin 2 = - (LEDK). Do NOT short + to - | 1
J4 | LED_R_EXT (1:+ 2:-) | Connector_PinHeader_2.54mm:PinHeader_1x02_P2.54mm_Vertical | PinHeader 1x02 2.54 mm |  | current-limited node (after R1/R3) | External LED: pin 1 = + (LEDA, after the series resistor), pin 2 = - (LEDK). Do NOT short + to - | 1
Q1,Q2 | AO3400A | Package_TO_SOT_SMD:SOT-23 | AO3400A (alt. Si2302CDS) | Alpha & Omega (alt. Vishay) | 30 V 5.7 A VGS(th) 0.65-1.45 V RDS(on)<48 mohm @2.5 V (alt. Si2302CDS 20 V 2.6 A 0.40-0.85 V <75 mohm) | SOT-23 pin 1=G 2=S 3=D. Gate driven by 3.3 V logic | 2
R1,R2 | 20 | Resistor_SMD:R_0603_1608Metric | chip resistor 20 ohm |  | 0.1 W (0603) | LED current limit @3V3 (20 ohm: 8.5/23.6/38.8 mA min/nom/max) | 2
R3,R4 | 33 | Resistor_SMD:R_2010_5025Metric | chip resistor 33 ohm |  | 0.5 W (2010) | LED current limit @5V (33 ohm 2010: 45/59/73 mA min/nom/max). Fitted, used only when SJ is set to 5V | 2
R5,R6 | 220 | Resistor_SMD:R_0603_1608Metric | chip resistor 220 ohm |  | 0.1 W (0603) | Gate series resistor (limits the gate charge peak to 15 mA) | 2
R7,R8 | 100k | Resistor_SMD:R_0603_1608Metric | chip resistor 100k ohm |  | 0.1 W (0603) | Gate pull-down: LED off during reset/boot (GPIO3 is a strapping pin) | 2
R9,R10 | 1 | Resistor_SMD:R_0603_1608Metric | chip resistor 1 ohm |  | 0.1 W (0603) 1 % | Current sense: TP ILED voltage = 1 mV per mA (1 %) | 2
R11 | 10k | Resistor_SMD:R_0603_1608Metric | chip resistor 10k ohm |  | 0.1 W (0603) | XSHUT pull-up (ST DS12385 2.4: XSHUT must always be driven; 10k recommended) | 1
R12 | 10k | Resistor_SMD:R_0603_1608Metric | chip resistor 10k ohm |  | 0.1 W (0603) | XSHUT pull-up (ST DS12385 2.4) | 1
R13 | 3.3k | Resistor_SMD:R_0603_1608Metric | chip resistor 3.3k ohm |  | 0.1 W (0603) | I2C pull-up. DNP: fit only if the module has none (ST Table 4: 3.6k for CL<=90 pF) | 1 | 未実装(DNP)
R14 | 3.3k | Resistor_SMD:R_0603_1608Metric | chip resistor 3.3k ohm |  | 0.1 W (0603) | I2C pull-up. DNP: fit only if the module has none | 1 | 未実装(DNP)
R15,R16 | 0 | Resistor_SMD:R_0603_1608Metric | chip resistor 0 ohm |  | 0 ohm jumper | GPIO1 link to XIAO D8/D9 (shares the Sense microSD SPI pins). Default: not fitted | 2 | 未実装(DNP)
SJ1 | LED_L_SUPPLY | Jumper:SolderJumper-3_P1.3mm_Bridged12_RoundedPad1.0x1.5mm | solder jumper (PCB pads) |  | - | Default: pads 1-2 bridged = 3V3 via R1/R2. For 5V: cut the 1-2 bridge, bridge 2-3 (via R3/R4) | 1
SJ2 | LED_R_SUPPLY | Jumper:SolderJumper-3_P1.3mm_Bridged12_RoundedPad1.0x1.5mm | solder jumper (PCB pads) |  | - | Default: pads 1-2 bridged = 3V3 via R1/R2. For 5V: cut the 1-2 bridge, bridge 2-3 (via R3/R4) | 1
U1 | XIAO_ESP32S3_Sense | head-sensor-board:XIAO_ESP32S3_THT_2x7_P2.54mm | Seeed XIAO ESP32S3 Sense |  | 3V3 out 700 mA (Seeed wiki, condition not stated) | Akizuki 118079. Mount on 2x 1x7 sockets (or pin headers). USB-C side = up in the drawing | 1

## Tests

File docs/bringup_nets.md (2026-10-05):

# 導通・短絡の確認表（回路図から `tools/gen_bringup_tables.py` が作る。手で直さない）

部品の実装前（基板だけ）と実装後に、テスターで確かめる（[bringup_plan.md](bringup_plan.md) の HG-K-03 / HG-K-04）。
ネット 25 本。「測りやすい点」= テストポイント（TPn）・ヘッダ（J1〜J4）のピン。XIAO は U1.n = ソケットのパッド（n = XIAO のピン番号。1〜7 が D0〜D6、8〜14 が D7, D8, D9, D10, 3V3, GND, 5V）。
**同じネットのパッドどうしは、間に部品が無ければ導通する。違うネットどうしは導通しない**（半田ジャンパー SJ の 1-2 は既定で橋渡しなので、SJ の A と LEDA は導通する）。

| ネット | パッド数 | つながるパッド（部品.ピン） | 測りやすい点 |
|---|---|---|---|
| `+3V3` | 13 | U1.12, C1.1, C2.1, C3.1, J1.1, J2.1, R1.1, R11.1, R12.1, R13.1, R14.1, R2.1, TP1.1 | J1.1, J2.1, TP1 |
| `GND` | 11 | U1.13, C1.2, C2.2, C3.2, J1.2, J2.2, R10.2, R7.2, R8.2, R9.2, TP2.1 | J1.2, J2.2, TP2 |
| `+5V` | 3 | U1.14, R3.1, R4.1 | （部品のパッドだけ） |
| `/D8_GPIO7` | 2 | U1.9, R15.1 | （部品のパッドだけ） |
| `/D9_GPIO8` | 2 | U1.10, R16.1 | （部品のパッドだけ） |
| `/GATE_L` | 3 | Q1.1, R5.2, R7.1 | （部品のパッドだけ） |
| `/GATE_R` | 3 | Q2.1, R6.2, R8.1 | （部品のパッドだけ） |
| `/LEDA_L` | 3 | D1.2, J3.1, SJ1.2 | J3.1 |
| `/LEDA_R` | 3 | D2.2, J4.1, SJ2.2 | J4.1 |
| `/LEDK_L` | 3 | D1.1, J3.2, Q1.3 | J3.2 |
| `/LEDK_R` | 3 | D2.1, J4.2, Q2.3 | J4.2 |
| `/LED_PWM_L` | 2 | U1.3, R5.1 | （部品のパッドだけ） |
| `/LED_PWM_R` | 2 | U1.4, R6.1 | （部品のパッドだけ） |
| `/SCL` | 5 | U1.6, J1.3, J2.3, R14.2, TP3.1 | J1.3, J2.3, TP3 |
| `/SDA` | 5 | U1.5, J1.4, J2.4, R13.2, TP4.1 | J1.4, J2.4, TP4 |
| `/SENSE_L` | 3 | Q1.2, R9.1, TP7.1 | TP7 |
| `/SENSE_R` | 3 | Q2.2, R10.1, TP8.1 | TP8 |
| `/TOF_L_INT` | 2 | J1.6, R15.2 | J1.6 |
| `/TOF_R_INT` | 2 | J2.6, R16.2 | J2.6 |
| `/XSHUT_L` | 4 | U1.1, J1.5, R11.2, TP5.1 | J1.5, TP5 |
| `/XSHUT_R` | 4 | U1.2, J2.5, R12.2, TP6.1 | J2.5, TP6 |
| `Net-(SJ1-A)` | 2 | R1.2, SJ1.1 | （部品のパッドだけ） |
| `Net-(SJ1-B)` | 2 | R3.2, SJ1.3 | （部品のパッドだけ） |
| `Net-(SJ2-A)` | 2 | R2.2, SJ2.1 | （部品のパッドだけ） |
| `Net-(SJ2-B)` | 2 | R4.2, SJ2.3 | （部品のパッドだけ） |

## 当たりをつける値（部品の実装後。電源を入れずに測る。値は回路図の部品表から）

| 測る 2 点 | 期待 | 外れたら |
|---|---|---|
| TP1（3V3）↔ TP2（GND） | **短絡していない**（数 kΩ 以上。コンデンサの充電で最初は低く見えて上がる） | 1 kΩ 未満 = はんだブリッジ。SJ・R1/R2・C1〜C3 まわりを見る |
| ゲート（Q1.1 / Q2.1）↔ GND | 約 100 kΩ（R7 / R8） | 開放 = R7/R8 の未はんだ。0 Ω = ブリッジ |
| XIAO の D2 / D3 のパッド（U1.3 / U1.4）↔ ゲート（Q1.1 / Q2.1） | 約 220 Ω（R5 / R6） | 開放 = R5/R6 の未はんだ |
| TP5 / TP6（XSHUT）↔ TP1（3V3） | 約 10 kΩ（R11 / R12） | 開放 = R11/R12 の未はんだ |
| TP7 / TP8（SENSE）↔ GND | 約 1 Ω（R9 / R10。テスターの導線の抵抗を引く） | 開放 = R9/R10 の未はんだ。数十 Ω 以上 = 接触不良 |
| SJ1 / SJ2 の pad1 ↔ pad2 | **導通（既定: はんだで橋渡し済み = 3V3）** | 開放 = 橋が切れている（5V 用に切った後なら正常） |
| SJ1 / SJ2 の pad2 ↔ pad3 | **開放**（既定） | 導通 = 3V3 と 5V がつながっている。**通電しない** |
| J3 / J4 の pin1（+）↔ pin2（−） | 抵抗レンジで**開放に見える**（間に D1 / D2 のダイオードがあるだけ） | 0 Ω に近い = **+ と − の短絡。R1 が約 0.5 W、R3 が約 0.7 W を消費して焼ける**。通電しない |
| J1 / J2 の各ピン ↔ 対応する TP・ソケットのパッド | 上の表のとおり導通 | 開放 = 配線・はんだの不良 |

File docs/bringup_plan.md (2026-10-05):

# head-sensor-board Rev A — 受け取り・組み立て・初回通電の確認手順（Human Gate）

**作成 2026-10-05（KiCad Agent）。** 基板はまだ発注していない。ここは「届いてからの人の作業」を、**何をどう測り、何が出れば合格か**まで決めておくための手順書。
**HARDWARE_VERIFIED = 0**（この基板の実機の測定は 1 つも無い）。以下の「期待値」は**設計からの計算値**（`docs/spec.md` §4、`tools/led_budget.py`）で、測った値ではない。**測定値を作り話で埋めない。**
所要時間はすべて Agent の**推定**。記録先 = `docs/bringup_log_YYYYMMDD.csv`（下の「返してほしい証拠」。無ければ新しく作る）。

順序: **HG-K-01（発注前）→ 02 → 03 → 04 → 05 → 06**。HG-K-07〜09 は ToF 小基板・XIAO Sense の現物が要る。前の Gate が不合格なら、次へ進まず Agent に結果を返す。
導通表: [bringup_nets.md](bringup_nets.md)（回路図から生成）。

| Gate | 何 | いつ | 先に要る Gate |
|---|---|---|---|
| HG-K-01 | 発注の前の確認（発注先・オプション・プレビュー） | 発注の前 | なし |
| HG-K-02 | 届いた基板の外観・寸法・刻印 | 受け取り | 発注 |
| HG-K-03 | 部品を載せる前の導通・短絡（基板だけ） | 受け取り | 02 |
| HG-K-04 | 実装（半田ジャンパー既定・DNP）と、実装後の導通・短絡 | 実装 | 03 |
| HG-K-05 | 初回通電（USB だけ、ToF なし、LED 消灯） | 実装後 | 04 |
| HG-K-06 | LED 電流（3V3、PWM）の測定 | 05 の後 | 05 |
| HG-K-07 | ToF 小基板のピン配置の記入 → I2C・XSHUT・アドレス変更 | 小基板が届いたら | 05 |
| HG-K-08 | ソケットの高さ・Sense 拡張ボード（カメラ・microSD）の出っ張り・組み付け | XIAO Sense とソケットが届いたら | 04 |
| HG-K-09 | LED を 5V にする試験（任意） | 06 の合格後、かつ XIAO の 5V 入力電流の測定（HT-015）の後 | 06 |

---

## HG-K-01 発注の前の確認

- **目的**: シルクの文字が潰れない発注先・オプションで発注する。
- **必要な物**: `gerbers/head-sensor-board_gerbers.zip`、発注先の注文ページ、`tools/fab_rules.json` の値（2026-10-05 に公開ページから取った値。**注文して確かめた値ではない**）。
- **手順**: ①発注先を決める。②**JLCPCB の標準の文字は高さ 1.0 mm 以上が必要で、この基板は 0.8 mm**（線幅 0.15 mm）。JLCPCB を使うなら注文画面で「高精度の文字（high-precision characters、0.8 mm 以上）」を選ぶ（追加費用の有無は未確認）。PCBWay・Elecrow は文字の高さ 0.8 mm 以上・線幅 0.15 mm 以上、Seeed Fusion は 0.58 mm 以上・0.10 mm 以上が最小なので、この基板（0.8 mm・0.15 mm）のままで可。③ZIP をアップロードして、発注先のオンラインのプレビューで、外形 44 × 28 mm、穴 2.2 mm ×2（取付穴）、シルク（J1/J2 の信号名、L / R、USB-C）を目で見る。④板厚 1.6 mm、2 層、銅厚・表面処理（ここでは指定なし。手はんだなので HASL 無鉛 / ENIG どちらも可）、数量を決める。
- **測定項目**: なし（確認のみ）。
- **期待**: プレビューで外形・穴・シルクが 3D ビュー（`docs/board_3d_top_noxiao.png`）と同じに見える。
- **失敗時**: シルクが欠ける・消える → Agent に画面のスクリーンショットを渡す（文字の太さ・高さの調整、または基板の高さを 28 → 29 mm 程度にして文字を 1.0 mm にする案がある。J1/J2 の信号名の 2 段が入る帯の計算では足りる見込みだが、実際に配置・配線して確かめたものではない。再配線が要る）。
- **返してほしい証拠**: プレビューのスクリーンショット、選んだ発注先とオプション。
- **合格基準**: プレビューで 4 項目（外形・取付穴・シルク・層構成）が OK。
- **安全**: なし。**発注は User の操作**（Agent はしない）。
- **推定時間**: 約 20 分。

## HG-K-02 届いた基板の外観・寸法・刻印

- **必要な物**: ノギス（0.05 mm）、拡大鏡またはスマホのマクロ、定規、基板。
- **手順・測定項目**: ①外形 縦・横（`docs/spec.md`: 44.0 × 28.0 mm、角 R1）。②取付穴 2 つの穴径（2.2 mm）と中心の位置（右の縁から 2.1 mm、上・下の縁から 2.1 mm）。③ビア・ヘッダの穴にレジストが詰まっていないか。④シルク: J1/J2 の 6 つの名前（右から VIN GND SCL SDA XSHUT GPIO1）、L / R、USB-C の矢印、TP の名前が読めるか。⑤ pin1（四角いパッド）が J1/J2 とも**右端**か。
- **期待**: 外形 ±0.2 mm（発注先の公開仕様の外形公差）。穴 2.2 mm ±0.1。文字が読める。
- **失敗時**: 寸法が ±0.3 mm を超える・穴の位置がずれる → 写真と値を Agent に。シルクが潰れる → HG-K-01 の案。
- **返してほしい証拠**: 寸法の表（値）、基板の表・裏の写真（真上から、ピントの合ったもの）。
- **合格基準**: ①〜⑤すべて OK。
- **推定時間**: 約 15 分。

## HG-K-03 部品を載せる前の導通・短絡（基板だけ）

- **目的**: 銅の短絡・断線を、部品を載せる前に見つける（直すのが一番楽）。
- **必要な物**: テスター（導通ブザーつき）、[bringup_nets.md](bringup_nets.md)。
- **手順**: ①電源を入れずに行う。② GND（TP2）とほかの全ネットのパッド（TP1・TP3〜TP8、ヘッダのピン、ソケットのパッド）の間を、導通ブザーで当たる。③ 3V3（TP1）とほかのネットの間を当たる。④ 隣り合うパッドの間（XIAO ソケットのパッド列、J1/J2 の隣り合うピン）を当たる。
- **測定項目**: 違うネットどうし（上の ②〜④）が**すべて導通しない**こと。同じネットのパッドが導通すること（[bringup_nets.md](bringup_nets.md) の表を数本、とくに SDA/SCL/XSHUT/GATE）。
- **期待**: 違うネットどうし = 導通なし（無限大）。同じネット = 導通あり（< 1 Ω）。**GND と 3V3 が短絡していない。**
- **失敗時**: 導通した 2 点（ネット名とパッド名）を Agent に。基板の不良（銅の不良）か、ゴミ・はんだくずかを、拡大鏡で見る。
- **返してほしい証拠**: 当てた組の一覧と結果（記録 CSV）。不良があれば写真。
- **合格基準**: 違うネットどうしの導通 0 件、同じネットの断線 0 件。
- **安全**: 通電しない。
- **推定時間**: 約 30 分。

## HG-K-04 実装と、実装後の導通・短絡

- **実装の既定**: **SJ1/SJ2 は pad1-pad2 を橋渡しした状態（= LED は 3V3、R1/R2 = 20 Ω）**。5V 用の R3/R4（33 Ω 2010）は実装する（SJ が 5V 側のときだけ使う）。**R13・R14（I2C のプルアップ）と R15・R16（0 Ω リンク）は未実装（DNP）**。XIAO はソケットに載せるのを**最後**にする（HG-K-05）。NSSW157T（D1/D2）はリフローかホットエア（樹脂を押さない。カソード側 = 大きいパッド = 左）。
- **手順・測定項目**（電源を入れずに）: [bringup_nets.md](bringup_nets.md) の「当たりをつける値」の表。**3V3（TP1）↔ GND（TP2）が短絡していない**、ゲート ↔ GND ≈ 100 kΩ、U1.3/U1.4 ↔ ゲート ≈ 220 Ω、TP5/TP6 ↔ 3V3 ≈ 10 kΩ、TP7/TP8 ↔ GND ≈ 1 Ω、SJ の pad1-pad2 導通・pad2-pad3 開放、J3/J4 の + ↔ − が抵抗レンジで開放。D1/D2 の向き: ダイオードテスト（またはテスターの 3 V 以上のレンジ）で、LEDA（J3 の pin1）に赤、LEDK（pin2）に黒を当てて順方向 約 2.7〜3.2 V（点灯する場合もある）。
- **期待**: 上のとおり。**抵抗値は ±5 %（R9/R10 は ±1 %）の範囲**（テスターの誤差を含めて ±10 % まで可）。
- **失敗時**: 外れた組と値を Agent に。**通電しない。**
- **返してほしい証拠**: 測定表（値）、実装後の基板の写真（表）。
- **合格基準**: 表の全項目が期待の範囲。3V3 ↔ GND が短絡していない。
- **安全**: 通電しない。J3/J4 の + と − を絶対に短絡しない（R1 約 0.5 W / R3 約 0.7 W で焼ける）。
- **推定時間**: 約 1.5 時間（はんだ付けを除く。実装の時間は別）。

## HG-K-05 初回通電（USB だけ、ToF なし、LED 消灯）

- **必要な物**: XIAO ESP32S3 Sense（ソケットに載せる。**拡張ボードはあってもなくてもよい**）、USB の電流計（USB パワーメーター）、テスター、PC。
- **手順**: ① XIAO をソケットに載せる（USB-C が基板の左の縁）。② **ファームを書き込まずに**（または LED・I2C を出さないスケッチ）USB で給電。③ 通電直後の USB 電流を読む。④ TP1（3V3）と TP2（GND）の電圧を測る。⑤ TP7/TP8（電流検出）が 0 付近か測る。
- **測定項目**: USB の電流（mA）、TP1 の電圧、TP7・TP8 の電圧。
- **期待**: TP1 = 約 3.3 V（Agent の想定は 3.2〜3.4 V。Seeed の仕様に精度の記載なし = 仮定）。TP7・TP8 ≈ 0 mV（LED 消灯。ゲートは 100 kΩ で GND に固定）。USB の電流は XIAO 単体の値（Seeed の値は条件不明）で、**500 mA を大きく下回る**。
- **失敗時**: TP1 が 3.2 V 未満・3.4 V 超、電流が 300 mA を超える、部品が熱い → **すぐ USB を抜く**。測定値と状況を Agent に。
- **返してほしい証拠**: USB パワーメーターの写真（電流・電圧）、TP1/TP7/TP8 の値、使ったファーム（または「書き込みなし」）。
- **合格基準**: TP1 が 3.2〜3.4 V、TP7/TP8 が 10 mV 未満、USB 電流が安定。
- **安全**: 部品が熱くなったら抜く。USB は PC のポートか電流制限つきの電源。
- **推定時間**: 約 20 分。

## HG-K-06 LED 電流（3V3、PWM）の測定

- **目的**: 設計の計算（3V3 で LED 1 個 8.5 / 23.6 / 38.8 mA）が実物で当たるかを見る。T4 の「明るさ × k」の基準になる（ENTRY-K-0001）。
- **手順**: ① 左の LED（D1）: D2（GPIO3）の PWM をデューティ 10 / 50 / 100 % に。② TP7（SENSE_L）と TP2（GND）の電圧を測る（**1 Ω の抵抗の両端なので、1 mV = 1 mA**）。③ 右の LED（D2）: D3（GPIO4）で、TP8 と TP2 を同様に。④ 暗い部屋で、LED の明るさをスマホ（露出固定）で撮る。
- **測定項目**: デューティごとの TP7 / TP8 の電圧（mV）。
- **期待（計算値）**: **デューティ 100 % で 8.5〜38.8 mV（公称 23.6 mV）**。10 % は DC 換算で約 1/10（テスターは平均値を示す。PWM の周波数と、テスターの応答による）。**LED を点灯させたままケースに入れない**（5V 側は別の Gate）。
- **失敗時**: 100 % でも 8 mV 未満、または 40 mV 超 → 値と状況を Agent に（VF のばらつき、R1 の値違い、MOSFET の向き違いを調べる）。左右で大きく違う（2 倍以上）→ 同。
- **返してほしい証拠**: 測定表、LED の写真。
- **合格基準**: 100 % で 8.5〜38.8 mV の範囲（テスターの誤差を含めて ±10 %）。
- **安全**: J3/J4 に外付け LED をつなぐ場合は、**+ と − を逆にしない・短絡しない**。
- **推定時間**: 約 30 分。

## HG-K-07 ToF 小基板のピン配置の記入 → I2C・XSHUT・アドレス変更

- **必要な物**: VL53L1X 小基板 ×2（Amazon B083Z316NC）、ジャンパー線 12 本、テスター、README の対応表、I2C スキャン用のスケッチ（無ければ Agent に依頼）。
- **手順**: ① 小基板の**印字とピンの数・ピッチ**を、README の「ToF 小基板のピン配置と、ジャンパー線の対応表」に記入する（**ここが作り話にならないように、現物を見て**）。② 小基板に**プルアップ・レギュレータ・レベルシフタがあるか**をテスターで確かめる（電源を入れずに、SDA/SCL とVIN の間の抵抗、等）。③ 対応表どおりにジャンパー線を J1/J2 へつなぐ（**VIN と GND を逆にしない**）。④ XSHUT を GPIO から制御して、**両方 L → 片方を上げて I2C アドレスを変更 → もう片方を上げる**。
- **測定項目**: I2C スキャンで見えるアドレス、SDA/SCL がアイドルで H（約 3.3 V）か（TP3/TP4）。
- **期待**: ST の既定アドレスは **0x29（7 bit）**。**片方だけ起動 → 0x29 だけ**、片方を別アドレスにした後 → **2 つ見える**。SDA/SCL のアイドル = 約 3.3 V。
- **失敗時**: 何も見えない → SDA/SCL のアイドル電圧を TP3/TP4 で測る。**約 0 V または浮いている → プルアップが無い**。その場合は R13/R14（3.3 kΩ、未実装）を実装して再試験。アドレスが違う、1 つしか見えない → 値を Agent に。
- **返してほしい証拠**: 記入した対応表（写真でも可）、スキャンの出力（ログ）、TP3/TP4 の電圧。
- **合格基準**: 2 個の小基板が別アドレスで見える。
- **安全**: 電源を入れる前に VIN/GND の向きを確認。
- **推定時間**: 約 1 時間。

## HG-K-08 ソケットの高さ・Sense 拡張ボードの出っ張り・組み付け

- **必要な物**: ノギス、購入したピンソケット（1×7 ×2）、XIAO ESP32S3 Sense（拡張ボード・カメラ・microSD を付けた状態）。
- **測定項目**: ①ソケットの高さ（基板の上面から、ソケットの上端まで。**設計の仮定は 8.5 mm**）。②XIAO の底面から基板までのすきまと、XIAO の下の最も背の高い部品（C1、0805、一般値 1.25 mm 以下）の高さ。③ XIAO + 拡張ボード + カメラ + microSD カード（差した状態）の外形が、XIAO の 21 × 17.8 mm の外へ**何 mm 出るか**（USB-C と反対の端、横）。④ J1/J2 のジャンパー線のコネクタを差したとき、XIAO・拡張ボードと触れないか。
- **期待**: ①約 8.5 mm（±1）。② C1 の上と XIAO の底面のすきま ≥ 3 mm。③出っ張りは 0〜（Seeed の wiki は全体 21 × 17.8 × 15 mm。**図面での確認はまだ**）。④触れない（XIAO の縁からコネクタの縁まで約 2.4 mm の設計）。
- **失敗時**: ②のすきまが小さい（直付けにした等）→ C1 を低い品に。③出っ張りが J1/J2・LED 側へ出る → 値と写真を Agent に（配置の見直し）。
- **返してほしい証拠**: ①〜④の値、横から見た写真（ノギスを当てたもの）。
- **合格基準**: ②≥ 3 mm、③出っ張りが設計の想定（XIAO の枠内 ±0.5 mm）、④触れない。
- **推定時間**: 約 30 分。

## HG-K-09 LED を 5V にする試験（任意）

- **前提**: **HG-K-06 が合格**、かつ **XIAO の 5V 入力電流の実測（Engineering の HT-015）が済んで、USB 2.0 の 500 mA に収まる見込み**（Agent の計算では 5V 合計 493 mA = 余裕 7 mA のため、**測らずに行わない**）。
- **手順**: ① SJ1（L）の pad1-pad2 の橋を**はんだ吸い取り線で切る**。② pad2-pad3 をはんだでつなぐ。③ USB パワーメーターを挟み、TP7 の電圧を測る（HG-K-06 と同じ要領）。④ 右（SJ2）も同様。
- **期待（計算値）**: LED 1 個 **45 / 59 / 73 mA（最小/公称/最大）= TP7 で 45〜73 mV**。USB 全体は 500 mA 未満。
- **失敗時**: USB が 450 mA を超える、R3/R4 が熱い（最悪で 176 mW、定格 0.5 W の 35 %）→ 抜く。
- **返してほしい証拠**: TP7/TP8 の値、USB パワーメーターの写真。
- **合格基準**: LED 電流が 45〜73 mA、USB 電流 < 500 mA（余裕を見て 450 mA 未満が望ましい）。
- **安全**: 5V は試験用の選択肢で、**既定は 3V3**。XIAO の 5V ピンの電流能力は Seeed に記載なし = **未確認**。J3/J4 の + − の短絡で R3 が約 0.7 W を消費して焼ける。
- **推定時間**: 約 30 分。

---

## 返してほしい証拠の書式（`docs/bringup_log_YYYYMMDD.csv`）

`gate,item,measured,unit,expected,pass,note,photo` の 1 行 1 測定。値は**測ったものだけ**（測れなかった項目は空欄にして理由を note へ）。写真は同じフォルダかファイル名で参照する。

## この手順書の限界

- 期待値は設計からの計算値。**実機で測るまで「確認済み」ではない。**
- ToF 小基板・XIAO Sense・ソケットの実物の仕様は未確認（`docs/spec.md` §8）。
- LED の光量・ToF の測距・I2C の波形の評価（T4 / T6）は、この基板の試験の後に Engineering / HG-H2 の手順で行う。

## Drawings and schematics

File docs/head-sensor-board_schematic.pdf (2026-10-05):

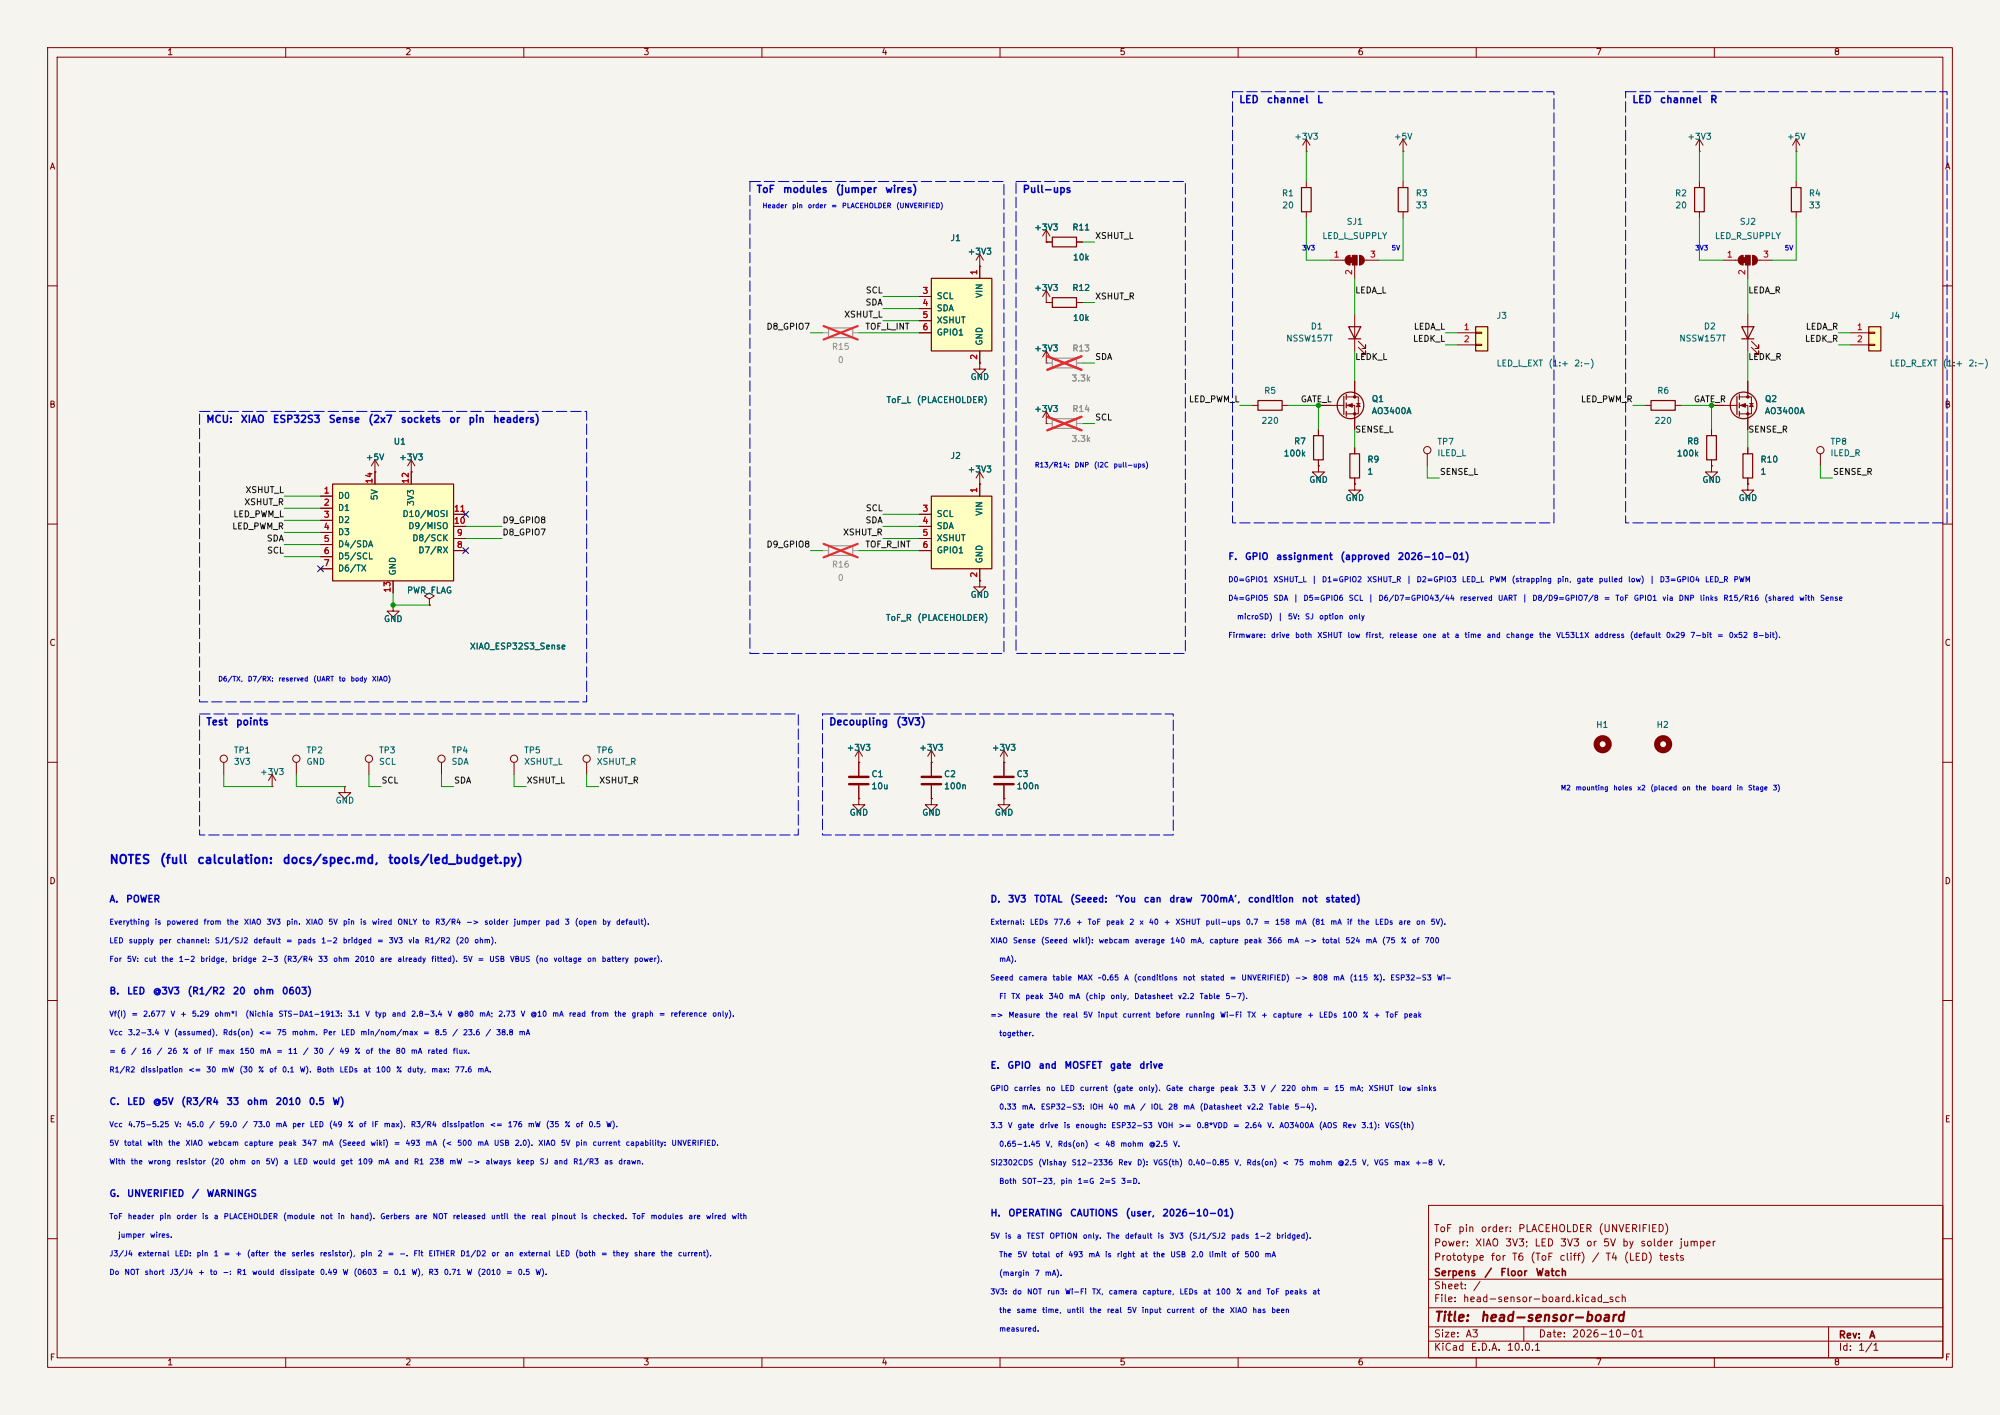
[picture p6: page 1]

ToF modules (jumper wires)

LEDA_L SENSE_L GATE_L Header pin order = PLACEHOLDER (UNVERIFIED)

5V NOTES (full calculation: docs/spec.md, tools/led_budget.py)

3V3 D. 3V3 TOTAL (Seeed: 'You can draw 700mA', condition not stated)

1 GND
ToF pin order: PLACEHOLDER (UNVERIFIED) VIN

MCU: XIAO ESP32S3 Sense (2x7 sockets or pin headers)

D0=GPIO1 XSHUT_L | D1=GPIO2 XSHUT_R | D2=GPIO3 LED_L PWM (strapping pin, gate pulled low) | D3=GPIO4 LED_R PWM

Firmware: drive both XSHUT low first, release one at a time and change the VL53L1X address (default 0x29 7-bit = 0x52 8-bit).

D6/TX, D7/RX: reserved (UART to body XIAO)

M2 mounting holes x2 (placed on the board in Stage 3)

Everything is powered from the XIAO 3V3 pin. XIAO 5V pin is wired ONLY to R3/R4 -> solder jumper pad 3 (open by default). For 5V: cut the 1-2 bridge, bridge 2-3 (R3/R4 33 ohm 2010 are already fitted). 5V = USB VBUS (no voltage on battery power).

External: LEDs 77.6 + ToF peak 2 x 40 + XSHUT pull-ups 0.7 = 158 mA (81 mA if the LEDs are on 5V).

LED supply per channel: SJ1/SJ2 default = pads 1-2 bridged = 3V3 via R1/R2 (20 ohm). Vcc 3.2-3.4 V (assumed), Rds(on) <= 75 mohm. Per LED min/nom/max = 8.5 / 23.6 / 38.8 mA

XIAO Sense (Seeed wiki): webcam average 140 mA, capture peak 366 mA -> total 524 mA (75 % of 700

5V is a TEST OPTION only. The default is 3V3 (SJ1/SJ2 pads 1-2 bridged). Si2302CDS (Vishay S12-2336 Rev D): VGS(th) 0.40-0.85 V, Rds(on) < 75 mohm @2.5 V, VGS max +-8 V. 3.3 V gate drive is enough: ESP32-S3 VOH >= 0.8*VDD = 2.64 V. AO3400A (AOS Rev 3.1): VGS(th) 0.33 mA. ESP32-S3: IOH 40 mA / IOL 28 mA (Datasheet v2.2 Table 5-4). GPIO carries no LED current (gate only). Gate charge peak 3.3 V / 220 ohm = 15 mA; XSHUT low sinks => Measure the real 5V input current before running Wi-Fi TX + capture + LEDs 100 % + ToF peak Seeed camera table MAX ~0.65 A (conditions not stated = UNVERIFIED) -> 808 mA (115 %). ESP32-S3 Wi-

B. LED @3V3 (R1/R2 20 ohm 0603) = 6 / 16 / 26 % of IF max 150 mA = 11 / 30 / 49 % of the 80 mA rated flux. R1/R2 dissipation <= 30 mW (30 % of 0.1 W). Both LEDs at 100 % duty, max: 77.6 mA. C. LED @5V (R3/R4 33 ohm 2010 0.5 W)

Fi TX peak 340 mA (chip only, Datasheet v2.2 Table 5-7).

Vf(I) = 2.677 V + 5.29 ohm*I (Nichia STS-DA1-1913: 3.1 V typ and 2.8-3.4 V @80 mA; 2.73 V @10 mA read from the graph = reference only). 5V total with the XIAO webcam capture peak 347 mA (Seeed wiki) = 493 mA (< 500 mA USB 2.0). XIAO 5V pin current capability: UNVERIFIED. ToF header pin order is a PLACEHOLDER (module not in hand). Gerbers are NOT released until the real pinout is checked. ToF modules are wired with

E. GPIO and MOSFET gate drive With the wrong resistor (20 ohm on 5V) a LED would get 109 mA and R1 238 mW -> always keep SJ and R1/R3 as drawn.

Vcc 4.75-5.25 V: 45.0 / 59.0 / 73.0 mA per LED (49 % of IF max). R3/R4 dissipation <= 176 mW (35 % of 0.5 W).

H. OPERATING CAUTIONS (user, 2026-10-01) Both SOT-23, pin 1=G 2=S 3=D.

Power: XIAO 3V3; LED 3V3 or 5V by solder jumper
Prototype for T6 (ToF cliff) / T4 (LED) tests
Serpens / Floor Watch
Sheet: /
File: head-sensor-board.kicad_sch
Title: head-sensor-board

J3/J4 external LED: pin 1 = + (after the series resistor), pin 2 = -. Fit EITHER D1/D2 or an external LED (both = they share the current).
(margin 7 mA). The 5V total of 493 mA is right at the USB 2.0 limit of 500 mA Do NOT short J3/J4 + to -: R1 would dissipate 0.49 W (0603 = 0.1 W), R3 0.71 W (2010 = 0.5 W).

the same time, until the real 5V input current of the XIAO has been 3V3: do NOT run Wi-Fi TX, camera capture, LEDs at 100 % and ToF peaks at

Size: A3 | Rev: A | F Date: 2026-10-01
KiCad E.D.A. 10.0.1 | Id: 1/1

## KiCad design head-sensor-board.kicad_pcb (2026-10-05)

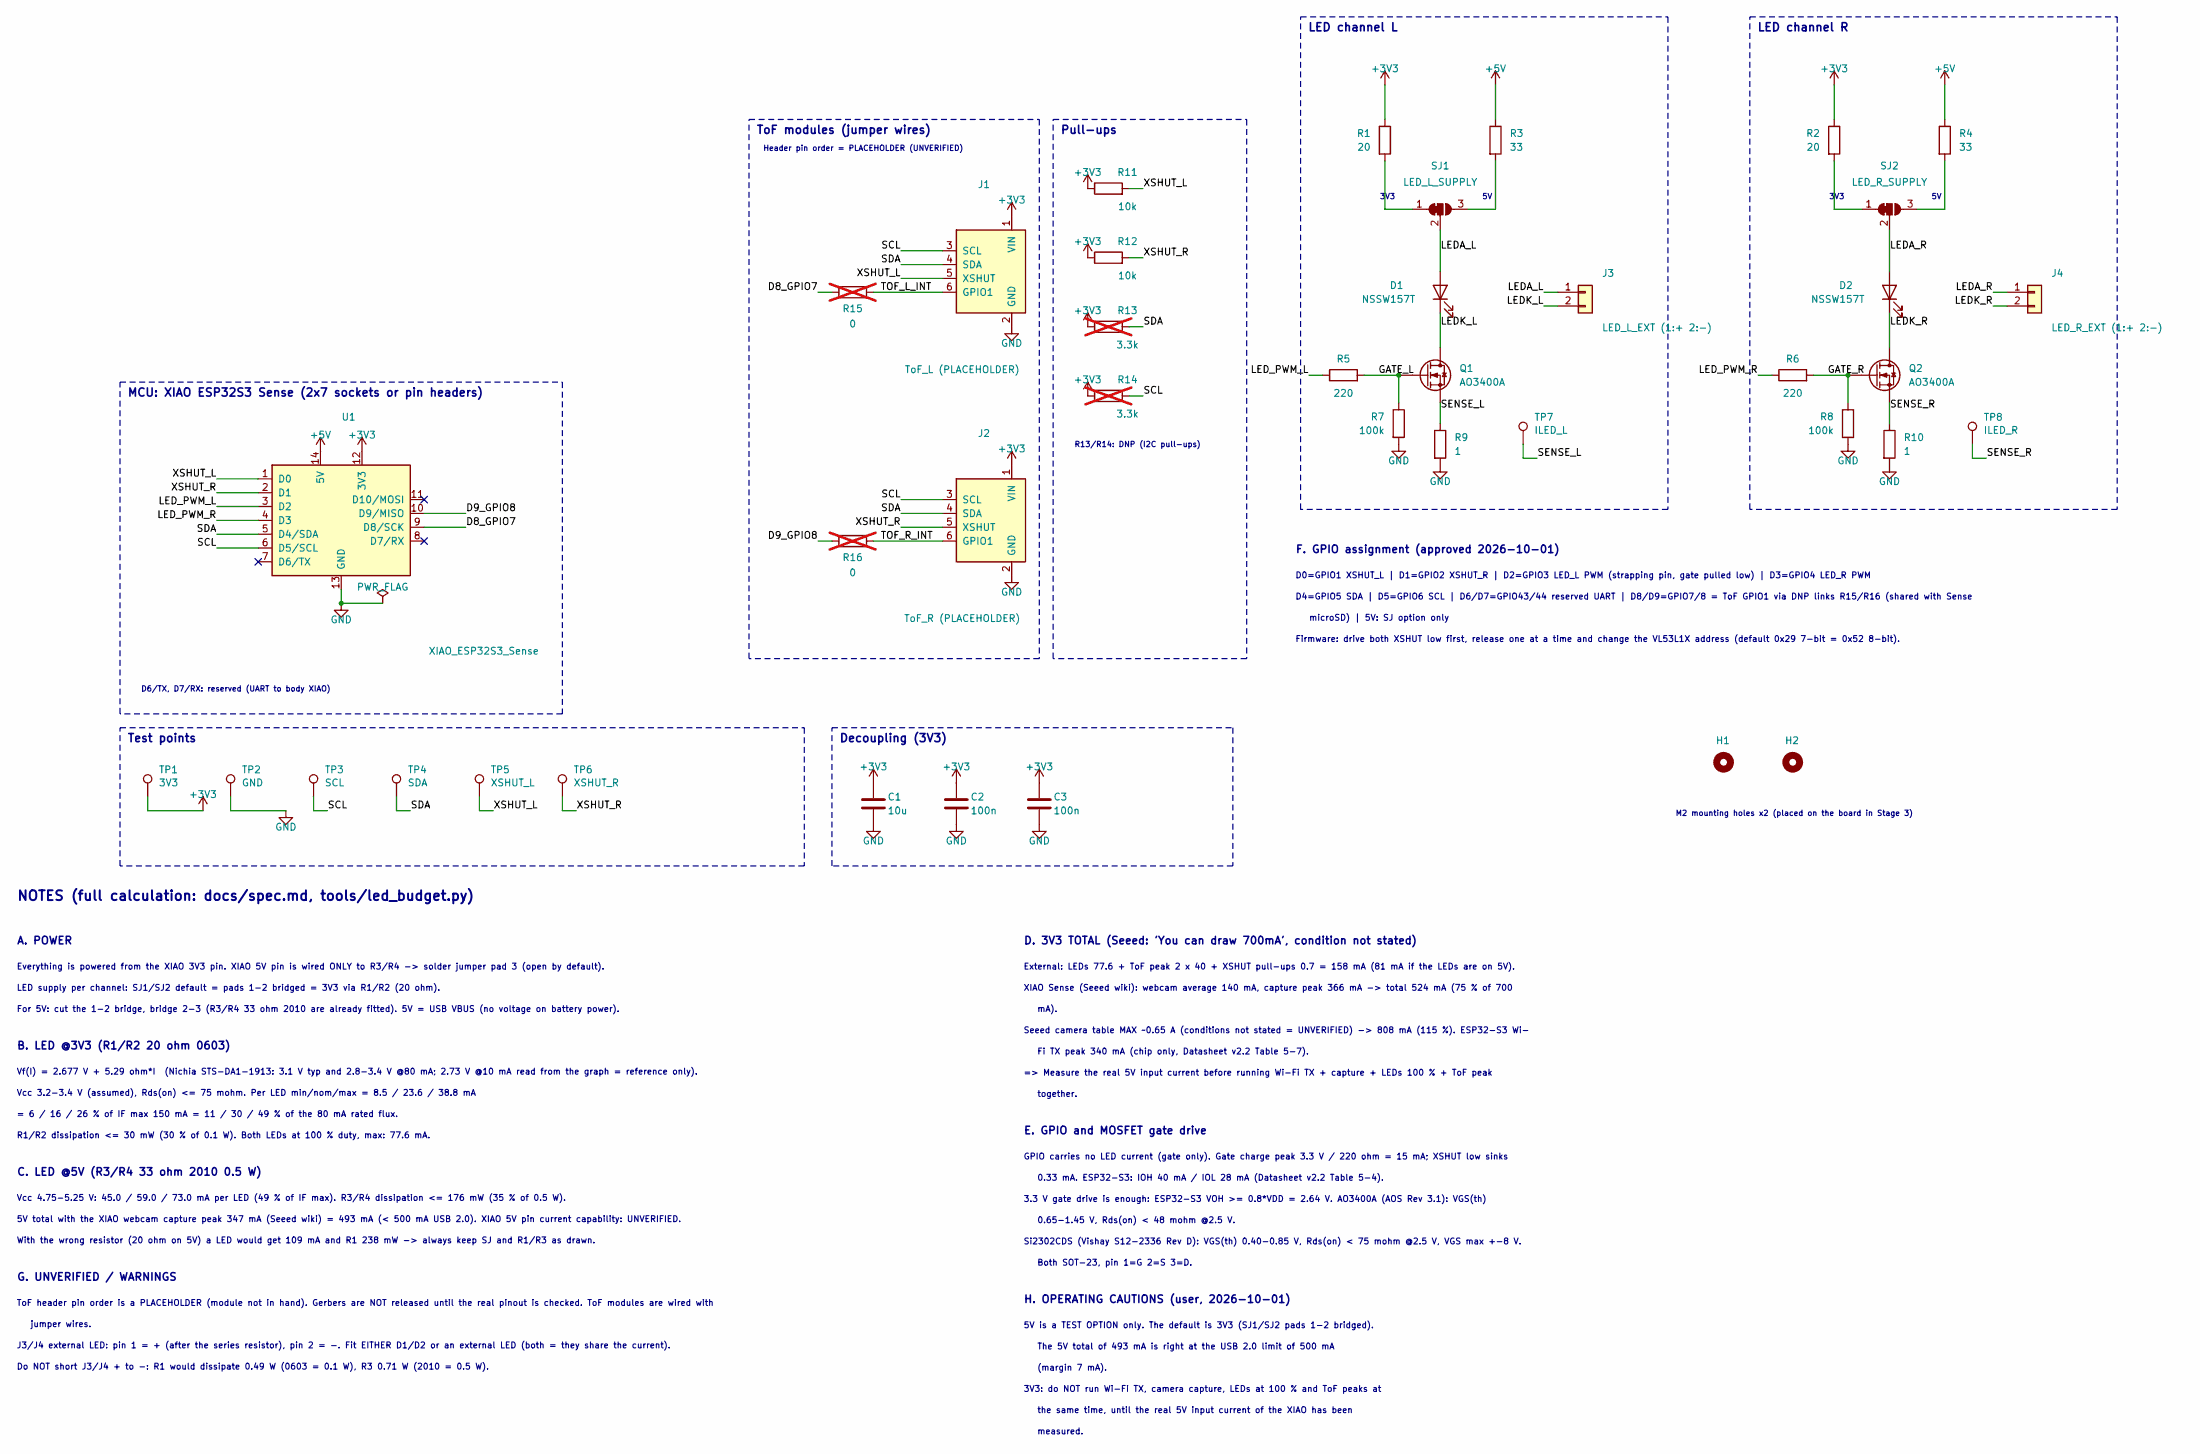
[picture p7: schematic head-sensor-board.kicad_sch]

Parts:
C1: 10u; C_0805_2012Metric; Rating 10 V X5R 0805; MPN ceramic capacitor 10uF
C2, C3: 100n; C_0603_1608Metric; Rating 16 V X7R 0603; MPN ceramic capacitor 100nF
D1, D2: NSSW157T; LED_Nichia_NSSW157T; Rating IF 150 mA max; VF 2.8-3.4 V @80 mA; 3.0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; MPN NSSW157T
H1, H2: MountingHole_2.2mm_M2; MPN M2 mounting hole (no part)
J1: ToF_L (PLACEHOLDER); PinHeader_1x06_P2.54mm_NoSilk; Rating 2.54 mm pitch; MPN PinHeader 1x06 2.54 mm
J2: ToF_R (PLACEHOLDER); PinHeader_1x06_P2.54mm_NoSilk; Rating 2.54 mm pitch; MPN PinHeader 1x06 2.54 mm
J3: LED_L_EXT (1:+ 2:-); PinHeader_1x02_P2.54mm_Vertical; Rating current-limited node (after R1/R3); MPN PinHeader 1x02 2.54 mm
J4: LED_R_EXT (1:+ 2:-); PinHeader_1x02_P2.54mm_Vertical; Rating current-limited node (after R1/R3); MPN PinHeader 1x02 2.54 mm
Q1, Q2: AO3400A; SOT-23; Rating 30 V 5.7 A VGS(th) 0.65-1.45 V RDS(on)<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; MPN AO3400A (alt. Si2302CDS)
R1, R2: 20; R_0603_1608Metric; Rating 0.1 W (0603); MPN chip resistor 20 ohm
R3, R4: 33; R_2010_5025Metric; Rating 0.5 W (2010); MPN chip resistor 33 ohm
R5, R6: 220; R_0603_1608Metric; Rating 0.1 W (0603); MPN chip resistor 220 ohm
R7, R8: 100k; R_0603_1608Metric; Rating 0.1 W (0603); MPN chip resistor 100k ohm
R9, R10: 1; R_0603_1608Metric; Rating 0.1 W (0603) 1 %; MPN chip resistor 1 ohm
R11, R12: 10k; R_0603_1608Metric; Rating 0.1 W (0603); MPN chip resistor 10k ohm
R13, R14: 3.3k; R_0603_1608Metric; Rating 0.1 W (0603); MPN chip resistor 3.3k ohm; not fitted
R15, R16: 0; R_0603_1608Metric; Rating 0 ohm jumper; MPN chip resistor 0 ohm; not fitted
SJ1: LED_L_SUPPLY; SolderJumper-3_P1.3mm_Bridged12_RoundedPad1.0x1.5mm; MPN solder jumper (PCB pads)
SJ2: LED_R_SUPPLY; SolderJumper-3_P1.3mm_Bridged12_RoundedPad1.0x1.5mm; MPN solder jumper (PCB pads)
TP1: 3V3; TestPoint_Pad_D1.5mm_NoSilk; MPN test point pad
TP2: GND; TestPoint_Pad_D1.5mm_NoSilk; MPN test point pad
TP3: SCL; TestPoint_Pad_D1.5mm_NoSilk; MPN test point pad
TP4: SDA; TestPoint_Pad_D1.5mm_NoSilk; MPN test point pad
TP5: XSHUT_L; TestPoint_Pad_D1.5mm_NoSilk; MPN test point pad
TP6: XSHUT_R; TestPoint_Pad_D1.5mm_NoSilk; MPN test point pad
TP7: ILED_L; TestPoint_Pad_D1.5mm_NoSilk; MPN test point pad
TP8: ILED_R; TestPoint_Pad_D1.5mm_NoSilk; MPN test point pad
U1: XIAO_ESP32S3_Sense; XIAO_ESP32S3_THT_2x7_P2.54mm; Rating 3V3 out 700 mA (Seeed wiki, condition n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; MPN Seeed XIAO ESP32S3 Sense

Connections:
+3V3: C1.1, C2.1, C3.1, J1.1 (VIN), J2.1 (VIN), R1.1, R2.1, R11.1, R12.1, R13.1, R14.1, TP1.1, U1.12 (3V3)
+5V: R3.1, R4.1, U1.14 (5V)
/D8_GPIO7: R15.1, U1.9 (D8/SCK)
/D9_GPIO8: R16.1, U1.10 (D9/MISO)
/GATE_L: Q1.1 (G), R5.2, R7.1
/GATE_R: Q2.1 (G), R6.2, R8.1
/LEDA_L: D1.2 (A), J3.1, SJ1.2 (C)
/LEDA_R: D2.2 (A), J4.1, SJ2.2 (C)
/LEDK_L: D1.1 (K), J3.2, Q1.3 (D)
/LEDK_R: D2.1 (K), J4.2, Q2.3 (D)
/LED_PWM_L: R5.1, U1.3 (D2)
/LED_PWM_R: R6.1, U1.4 (D3)
/SCL: J1.3 (SCL), J2.3 (SCL), R14.2, TP3.1, U1.6 (D5/SCL)
/SDA: J1.4 (SDA), J2.4 (SDA), R13.2, TP4.1, U1.5 (D4/SDA)
/SENSE_L: Q1.2 (S), R9.1, TP7.1
/SENSE_R: Q2.2 (S), R10.1, TP8.1
/TOF_L_INT: J1.6 (GPIO1), R15.2
/TOF_R_INT: J2.6 (GPIO1), R16.2
/XSHUT_L: J1.5 (XSHUT), R11.2, TP5.1, U1.1 (D0)
/XSHUT_R: J2.5 (XSHUT), R12.2, TP6.1, U1.2 (D1)
GND: C1.2, C2.2, C3.2, J1.2 (GND), J2.2 (GND), R7.2, R8.2, R9.2, R10.2, TP2.1, U1.13 (GND)
unnamed: R1.2, SJ1.1 (A)
unnamed: R3.2, SJ1.3 (B)
unnamed: R2.2, SJ2.1 (A)
unnamed: R4.2, SJ2.3 (B)

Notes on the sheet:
MCU: XIAO ESP32S3 Sense (2x7 sockets or pin headers)
D6/TX, D7/RX: reserved (UART to body XIAO)
ToF modules (jumper wires)
Header pin order = PLACEHOLDER (UNVERIFIED)
Pull-ups
R13/R14: DNP (I2C pull-ups)
LED channel L
3V3
LED channel R
Test points
Decoupling (3V3)
M2 mounting holes x2 (placed on the board in Stage 3)
NOTES (full calculation: docs/spec.md, tools/led_budget.py)
A. POWER
Everything is powered from the XIAO 3V3 pin. XIAO 5V pin is wired ONLY to R3/R4 -> solder jumper pad 3 (open by default).
LED supply per channel: SJ1/SJ2 default = pads 1-2 bridged = 3V3 via R1/R2 (20 ohm).
For 5V: cut the 1-2 bridge, bridge 2-3 (R3/R4 33 ohm 2010 are already fitted). 5V = USB VBUS (no voltage on battery power).
B. LED @3V3 (R1/R2 20 ohm 0603)
Vf(I) = 2.677 V + 5.29 ohm*I (Nichia STS-DA1-1913: 3.1 V typ and 2.8-3.4 V @80 mA; 2.73 V @10 mA read from the graph = reference only).
Vcc 3.2-3.4 V (assumed), Rds(on) <= 75 mohm. Per LED min/nom/max = 8.5 / 23.6 / 38.8 mA
= 6 / 16 / 26 % of IF max 150 mA = 11 / 30 / 49 % of the 80 mA rated flux.
R1/R2 dissipation <= 30 mW (30 % of 0.1 W). Both LEDs at 100 % duty, max: 77.6 mA.
C. LED @5V (R3/R4 33 ohm 2010 0.5 W)
Vcc 4.75-5.25 V: 45.0 / 59.0 / 73.0 mA per LED (49 % of IF max). R3/R4 dissipation <= 176 mW (35 % of 0.5 W).
5V total with the XIAO webcam capture peak 347 mA (Seeed wiki) = 493 mA (< 500 mA USB 2.0). XIAO 5V pin current capability: UNVERIFIED.
With the wrong resistor (20 ohm on 5V) a LED would get 109 mA and R1 238 mW -> always keep SJ and R1/R3 as drawn.
G. UNVERIFIED / WARNINGS
ToF header pin order is a PLACEHOLDER (module not in hand). Gerbers are NOT released until the real pinout is checked. ToF modules are wired with
jumper wires.
J3/J4 external LED: pin 1 = + (after the series resistor), pin 2 = -. Fit EITHER D1/D2 or an external LED (both = they share the current).
Do NOT short J3/J4 + to -: R1 would dissipate 0.49 W (0603 = 0.1 W), R3 0.71 W (2010 = 0.5 W).
D. 3V3 TOTAL (Seeed: 'You can draw 700mA', condition not stated)
External: LEDs 77.6 + ToF peak 2 x 40 + XSHUT pull-ups 0.7 = 158 mA (81 mA if the LEDs are on 5V).
XIAO Sense (Seeed wiki): webcam average 140 mA, capture peak 366 mA -> total 524 mA (75 % of 700
mA).
Seeed camera table MAX ~0.65 A (conditions not stated = UNVERIFIED) -> 808 mA (115 %). ESP32-S3 Wi-
Fi TX peak 340 mA (chip only, Datasheet v2.2 Table 5-7).
=> Measure the real 5V input current before running Wi-Fi TX + capture + LEDs 100 % + ToF peak
together.
E. GPIO and MOSFET gate drive

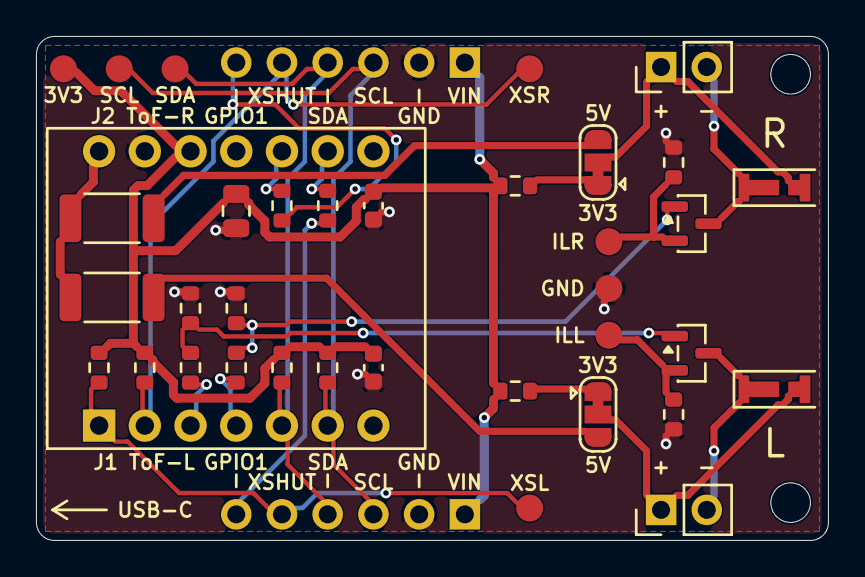
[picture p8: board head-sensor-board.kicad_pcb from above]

Board: 2 copper layers, 44.0 x 28.0 mm, 40 parts (0 on the bottom side), 25 nets.

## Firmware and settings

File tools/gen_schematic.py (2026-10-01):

#!/usr/bin/env python3
"""head-sensor-board の回路図（KiCad 10 形式）を生成する。

    python tools/gen_schematic.py          # head-sensor-board.kicad_sch を上書きする

注意: KiCad で回路図を手で直した後にこれを実行すると、手直しが消える。
      手で直したら、このスクリプトは「再生成用の参考」として使い、上書きしない。
電流の数値は tools/led_budget.py から取り込む（注記と計算が食い違わないように）。
"""
import math
import pathlib
import re
import sys
import uuid

sys.path.insert(0, str(pathlib.Path(__file__).resolve().parent))
import led_budget as lb                       # noqa: E402
from kicad_sexpr import SymbolLibrary          # noqa: E402

ROOT = pathlib.Path(__file__).resolve().parent.parent
OUT = ROOT / "head-sensor-board.kicad_sch"
STD = pathlib.Path(r"C:\Program Files\KiCad\10.0\share\kicad\symbols")
PROJECT = "head-sensor-board"
NS = uuid.UUID("6f1c2f0e-8c1e-4f5e-9d3a-5a1b7c0de001")
G = 1.27


def g(n):
    return round(n * G, 4)


def fmt(v):
    s = f"{v:.4f}".rstrip("0").rstrip(".")
    return "0" if s in ("", "-0") else s


_root_uuid = re.search(r'\(uuid "([^"]+)"\)', OUT.read_text(encoding="utf-8")).group(1)


def uid(key):
    return str(uuid.uuid5(NS, key))


LIBS = {}


def lib(nick):
    if nick not in LIBS:
        path = ROOT / "libs" / "head-sensor-board.kicad_sym" if nick == "head-sensor-board" else STD / f"{nick}.kicad_sym"
        LIBS[nick] = SymbolLibrary(path)
    return LIBS[nick]


DIRV = {"E": (1, 0), "W": (-1, 0), "N": (0, -1), "S": (0, 1)}      # 画面座標（y は下向き）


def rotate(v, rot):
    x, y = v
    for _ in range((rot // 90) % 4):
        x, y = -y, x
    return x, y


class Sch:
    def __init__(self):
        self.items = []            # 回路図の本体に出す要素（テキスト）
        self.used = {}             # lib_id -> True
        self.parts = {}            # ref -> dict
        self.pwr_n = 0
        self.seq = 0

    # ---------------------------------------------------------------- 基本要素
    def _id(self, what):
        self.seq += 1
        return uid(f"{what}:{self.seq}")

    def wire(self, p1, p2):
        self.items.append(
            f'\t(wire\n\t\t(pts\n\t\t\t(xy {fmt(p1[0])} {fmt(p1[1])}) (xy {fmt(p2[0])} {fmt(p2[1])})\n\t\t)\n'
            f'\t\t(stroke\n\t\t\t(width 0)\n\t\t\t(type default)\n\t\t)\n\t\t(uuid "{self._id("wire")}")\n\t)\n')

    def path(self, *pts):
        for a, b in zip(pts, pts[1:]):
            self.wire(a, b)

    def junction(self, p):
        self.items.append(f'\t(junction\n\t\t(at {fmt(p[0])} {fmt(p[1])})\n\t\t(diameter 0)\n\t\t(color 0 0 0 0)\n\t\t(uuid "{self._id("jn")}")\n\t)\n')

    def no_connect(self, p):
        self.items.append(f'\t(no_connect\n\t\t(at {fmt(p[0])} {fmt(p[1])})\n\t\t(uuid "{self._id("nc")}")\n\t)\n')

    def label(self, net, p, direction="E"):
        ang, just = {"E": (0, "left bottom"), "W": (180, "right bottom"), "N": (90, "left bottom"), "S": (270, "right bottom")}[direction]
        self.items.append(
            f'\t(label "{net}"\n\t\t(at {fmt(p[0])} {fmt(p[1])} {ang})\n\t\t(effects\n\t\t\t(font\n\t\t\t\t(size 1.27 1.27)\n\t\t\t)\n'
            f'\t\t\t(justify {just})\n\t\t)\n\t\t(uuid "{self._id("lbl")}")\n\t)\n')

    def text(self, s, p, size=1.27, bold=False):
        s = s.replace("\\", "/").replace('"', "'").replace("\n", "\\n")
        b = "\n\t\t\t\t(bold yes)" if bold else ""
        self.items.append(
            f'\t(text "{s}"\n\t\t(exclude_from_sim no)\n\t\t(at {fmt(p[0])} {fmt(p[1])} 0)\n\t\t(effects\n\t\t\t(font\n'
            f'\t\t\t\t(size {size} {size}){b}\n\t\t\t)\n\t\t\t(justify left bottom)\n\t\t)\n\t\t(uuid "{self._id("txt")}")\n\t)\n')

    def box(self, p1, p2, title=None):
        self.items.append(
            f'\t(rectangle\n\t\t(start {fmt(p1[0])} {fmt(p1[1])})\n\t\t(end {fmt(p2[0])} {fmt(p2[1])})\n\t\t(stroke\n'
            f'\t\t\t(width 0.2)\n\t\t\t(type dash)\n\t\t)\n\t\t(fill\n\t\t\t(type none)\n\t\t)\n\t\t(uuid "{self._id("box")}")\n\t)\n')
        if title:
            self.text(title, (p1[0] + 1.27, p1[1] + 3.0), 1.5, bold=True)

    # ---------------------------------------------------------------- 部品
    @staticmethod
    def _prop(name, value, x, y, rot=0, hide=False, justify=None):
        value = str(value).replace('"', "'")
        h = "\n\t\t\t(hide yes)" if hide else ""
        j = f"\n\t\t\t\t(justify {justify})" if justify and justify != "center" else ""   # 中央寄せは指定なし
        return (f'\t\t(property "{name}" "{value}"\n\t\t\t(at {fmt(x)} {fmt(y)} {rot}){h}\n\t\t\t(show_name no)\n\t\t\t(do_not_autoplace no)\n'
                f'\t\t\t(effects\n\t\t\t\t(font\n\t\t\t\t\t(size 1.27 1.27)\n\t\t\t\t){j}\n\t\t\t)\n\t\t)\n')

    def place(self, lib_id, ref, value, at, rot=0, footprint="", fields=None, dnp=False, in_bom=True, on_board=True,
              ref_off=None, val_off=None, hide_ref=False, hide_val=False, datasheet="", description=""):
        nick, name = lib_id.split(":")
        self.used[lib_id] = True
        pins = lib(nick).pins(name)
        x, y = at
        pos = {}
        for num, p in pins.items():
            rx, ry = rotate((round(p["x"], 4), round(p["y"], 4)), rot)            # y 上向き系で回転
            a = math.radians(p["angle"])                                           # ピン端 → 本体 の向き（y 上向き系）
            ox, oy = rotate((-round(math.cos(a)), -round(math.sin(a))), rot)       # 外向き（y 上向き系）
            d = {(1, 0): "E", (-1, 0): "W", (0, 1): "N", (0, -1): "S"}[(ox, oy)]   # 画面では y が下向き: 上 = N
            pos[num] = dict(xy=(round(x + rx, 4), round(y - ry, 4)), dir=d, name=p["name"])
        self.parts[ref] = dict(at=at, rot=rot, pins=pos)
        ro = ref_off or (2.54, -1.27, "left")
        vo = val_off or (2.54, 1.27, "left")
        fa = 90 if rot in (90, 270) else 0          # 回転した部品のフィールドは相対角で書かれる
        props = ""
        props += self._prop("Reference", ref, x + ro[0], y + ro[1], fa, hide_ref, ro[2])
        props += self._prop("Value", value, x + vo[0], y + vo[1], fa, hide_val, vo[2])
        props += self._prop("Footprint", footprint, x, y, 0, True)
        props += self._prop("Datasheet", datasheet, x, y, 0, True)
        props += self._prop("Description", description, x, y, 0, True)
        for k, v in (fields or {}).items():
            props += self._prop(k, v, x, y, 0, True)
        pin_txt = "".join(f'\t\t(pin "{n}"\n\t\t\t(uuid "{uid(f"pin:{ref}:{n}")}")\n\t\t)\n' for n in sorted(pins, key=lambda s: (len(s), s)))
        blk = (f'\t(symbol\n\t\t(lib_id "{lib_id}")\n\t\t(at {fmt(x)} {fmt(y)} {rot})\n\t\t(unit 1)\n\t\t(body_style 1)\n\t\t(exclude_from_sim no)\n'
               f'\t\t(in_bom {"yes" if in_bom else "no"})\n\t\t(on_board {"yes" if on_board else "no"})\n\t\t(in_pos_files yes)\n'
               f'\t\t(dnp {"yes" if dnp else "no"})\n\t\t(fields_autoplaced yes)\n\t\t(uuid "{uid("sym:" + ref)}")\n{props}{pin_txt}'
               f'\t\t(instances\n\t\t\t(project "{PROJECT}"\n\t\t\t\t(path "/{_root_uuid}"\n\t\t\t\t\t(reference "{ref}")\n\t\t\t\t\t(unit 1)\n'
               f'\t\t\t\t)\n\t\t\t)\n\t\t)\n\t)\n')
        self.items.append(blk)
        return ref

    def pin(self, ref, num):
        return self.parts[ref]["pins"][str(num)]["xy"]

    def dir(self, ref, num):
        return self.parts[ref]["pins"][str(num)]["dir"]

    def power(self, sym, at, hide_val=False):
        """電源シンボルを at（= ピンの位置）に置く。"""
        self.pwr_n += 1
        ref = f"#PWR{self.pwr_n:02d}" if sym != "PWR_FLAG" else f"#FLG{self.pwr_n:02d}"
        name = sym
        x, y = at
        val_off = (0, -3.0) if sym in ("+3V3", "+5V", "PWR_FLAG") else (0, 3.0)
        lib_id = f"power:{name}"
        self.used[lib_id] = True
        self.parts[ref] = dict(at=at, rot=0, pins={"1": dict(xy=at, dir="N" if sym != "GND" else "S", name="")})
        props = (self._prop("Reference", ref, x, y + 3.81 if sym != "GND" else y - 3.81, 0, True)
                 + self._prop("Value", sym, x + val_off[0], y + val_off[1], 0, hide_val)
                 + self._prop("Footprint", "", x, y, 0, True) + self._prop("Datasheet", "", x, y, 0, True)
                 + self._prop("Description", f'Power symbol creates a global label with name "{sym}"', x, y, 0, True))
        self.items.append(
            f'\t(symbol\n\t\t(lib_id "{lib_id}")\n\t\t(at {fmt(x)} {fmt(y)} 0)\n\t\t(unit 1)\n\t\t(body_style 1)\n\t\t(exclude_from_sim no)\n'
            f'\t\t(in_bom no)\n\t\t(on_board no)\n\t\t(in_pos_files no)\n\t\t(dnp no)\n\t\t(fields_autoplaced yes)\n\t\t(uuid "{uid("pwr:" + ref)}")\n{props}'
            f'\t\t(pin "1"\n\t\t\t(uuid "{uid("pwrpin:" + ref)}")\n\t\t)\n'
            f'\t\t(instances\n\t\t\t(project "{PROJECT}"\n\t\t\t\t(path "/{_root_uuid}"\n\t\t\t\t\t(reference "{ref}")\n\t\t\t\t\t(unit 1)\n\t\t\t\t)\n\t\t\t)\n\t\t)\n\t)\n')
        return at

    # ---------------------------------------------------------------- 接続の補助
    def stub(self, ref, num, net, length=2.54):
        """ピンの端から外向きに短い線を引き、ラベルを付ける。上下向きのピンは L 字にして文字を横向きにする。"""
        p = self.pin(ref, num)
        d = self.dir(ref, num)
        vx, vy = DIRV[d]
        if d in ("E", "W"):
            e = (round(p[0] + vx * length, 4), p[1])
            self.wire(p, e)
            self.label(net, e, d)
        else:
            m = (p[0], round(p[1] + vy * 2.54, 4))
            e = (round(m[0] + 2.54, 4), m[1])
            self.path(p, m, e)
            self.label(net, e, "E")
        return e

    def lib_symbols_text(self):
        out = []
        for lib_id in sorted(self.used):
            nick, name = lib_id.split(":")
            out.append(lib(nick).lib_symbol_text(nick, name, 2))
        return "\t(lib_symbols\n" + "\n".join(out) + "\n\t)\n"


def build():
    s = Sch()
    today = "2026-10-01"

    # ------------------------------------------------------------------ 数値（led_budget.py から）
    lo3, nom3, hi3 = lb.stats(lb.VCC3, 20)
    lo5, nom5, hi5 = lb.stats(lb.VCC5, 33)
    led3 = lb.N_LED * hi3
    tof_pk = lb.N_TOF * lb.TOF_PEAK
    ext3 = led3 + tof_pk + 2 * lb.XSHUT_PU
    ext5 = tof_pk + 2 * lb.XSHUT_PU
    tB = lb.XIAO_WEBCAM_PEAK_BAT + ext3
    tC = lb.XIAO_CAM_TABLE_MAX + ext3
    sens = lb.R_SENSE + lb.R_DS
    short3 = 3.3 / (20 + sens)
    short5 = 5.0 / (33 + sens)
    mA = lambda a: f"{a * 1e3:.1f}"            # noqa: E731
    I0 = lambda a: f"{a * 1e3:.0f}"            # noqa: E731

    # ------------------------------------------------------------------ 共通の属性
    R0603 = "Resistor_SMD:R_0603_1608Metric"
    R2010 = "Resistor_SMD:R_2010_5025Metric"

    def res(ref, value, at, rot, fp, note, rating, dnp=False, **kw):
        return s.place("Device:R", ref, value, at, rot, fp,
                       fields={"MPN": f"chip resistor {value} ohm", "Rating": rating, "Notes": note}, dnp=dnp, **kw)

    # ------------------------------------------------------------------ U1（XIAO）
    U = (g(65), g(88))
    s.box((g(33), g(68)), (g(97), g(116)), "MCU: XIAO ESP32S3 Sense (2x7 sockets or pin headers)")
    s.place("head-sensor-board:XIAO_ESP32S3", "U1", "XIAO_ESP32S3_Sense", U, 0,
            "head-sensor-board:XIAO_ESP32S3_THT_2x7_P2.54mm",
            fields={"MPN": "Seeed XIAO ESP32S3 Sense", "Rating": "3V3 out 700 mA (Seeed wiki, condition not stated)",
                    "Notes": "Akizuki 118079. Mount on 2x 1x7 sockets (or pin headers). USB-C side = up in the drawing"},
            ref_off=(0, -19.0, "left"), val_off=(16.0, 24.0, "left"), datasheet="https://wiki.seeedstudio.com/xiao_esp32s3_getting_started/")
    for num, net in ((1, "XSHUT_L"), (2, "XSHUT_R"), (3, "LED_PWM_L"), (4, "LED_PWM_R"), (5, "SDA"), (6, "SCL")):
        s.stub("U1", num, net, 7.62)
    s.no_connect(s.pin("U1", 7))
    s.text("D6/TX, D7/RX: reserved (UART to body XIAO)", (g(36), g(113)), 1.0)
    s.no_connect(s.pin("U1", 11))                                   # D10 unused
    s.stub("U1", 10, "D9_GPIO8", 7.62)
    s.stub("U1", 9, "D8_GPIO7", 7.62)
    s.no_connect(s.pin("U1", 8))                                     # D7/RX reserved
    s.power("+5V", s.pin("U1", 14))
    s.power("+3V3", s.pin("U1", 12))
    g13 = s.pin("U1", 13)
    gnd_end = (g13[0], round(g13[1] + 2.54, 4))
    s.wire(g13, gnd_end)
    s.power("GND", gnd_end)
    flg = (round(gnd_end[0] + 7.62, 4), gnd_end[1])
    s.wire(gnd_end, flg)
    s.junction(gnd_end)
    s.power("PWR_FLAG", flg)

    # ------------------------------------------------------------------ ToF ヘッダ（ジャンパー線で離して置く）
    s.box((g(124), g(30)), (g(166), g(108)), "ToF modules (jumper wires)")
    s.text("Header pin order = PLACEHOLDER (UNVERIFIED)", (g(126), g(34) + 1.0), 1.0)
    tof_fields = {"MPN": "PinHeader 1x06 2.54 mm", "Rating": "2.54 mm pitch",
                  "Notes": "VL53L1X small module (Amazon B083Z316NC) on jumper wires. PIN ORDER IS A PLACEHOLDER - UNVERIFIED (module not in hand)"}
    for ref, val, at, sh, inte, dnet in (("J1", "ToF_L (PLACEHOLDER)", (g(158), g(52)), "XSHUT_L", "TOF_L_INT", "D8_GPIO7"),
                                          ("J2", "ToF_R (PLACEHOLDER)", (g(158), g(88)), "XSHUT_R", "TOF_R_INT", "D9_GPIO8")):
        s.place("head-sensor-board:ToF_Header_1x06", ref, val, at, 0, "head-sensor-board:PinHeader_1x06_P2.54mm_NoSilk",
                fields=tof_fields, ref_off=(0, -16.0, "center"), val_off=(-4.0, 18.0, "center"))
        s.power("+3V3", s.pin(ref, 1))
        s.power("GND", s.pin(ref, 2))
        s.stub(ref, 3, "SCL", 7.62)
        s.stub(ref, 4, "SDA", 7.62)
        s.stub(ref, 5, sh, 7.62)
        # GPIO1 -> 0 ohm link (DNP) -> XIAO D8 / D9
        p6 = s.pin(ref, 6)
        lref = "R15" if ref == "J1" else "R16"
        lx = round(p6[0] - 12.7 - 3.81, 4)
        res(lref, "0", (lx, p6[1]), 90, R0603, "GPIO1 link to XIAO D8/D9 (shares the Sense microSD SPI pins). Default: not fitted",
            "0 ohm jumper", dnp=True, ref_off=(0, 3.0, "center"), val_off=(0, 5.8, "center"))
        s.wire(p6, s.pin(lref, 2))
        s.stub(lref, 1, dnet, 2.54)
        s.label(inte, (round(s.pin(lref, 2)[0] + 1.27, 4), p6[1]), "E")

    # ------------------------------------------------------------------ プルアップ（XSHUT は実装、I2C は DNP）
    s.box((g(168), g(30)), (g(196), g(108)), "Pull-ups")
    px = g(173)
    for i, (ref, val, net, dnp, note) in enumerate((
            ("R11", "10k", "XSHUT_L", False, "XSHUT pull-up (ST DS12385 2.4: XSHUT must always be driven; 10k recommended)"),
            ("R12", "10k", "XSHUT_R", False, "XSHUT pull-up (ST DS12385 2.4)"),
            ("R13", "3.3k", "SDA", True, "I2C pull-up. DNP: fit only if the module has none (ST Table 4: 3.6k for CL<=90 pF)"),
            ("R14", "3.3k", "SCL", True, "I2C pull-up. DNP: fit only if the module has none"))):
        y = g(40) + i * g(10)
        res(ref, val, (round(px + 3.81, 4), y), 90, R0603, note, "0.1 W (0603)", dnp=dnp, ref_off=(3.5, -3.0, "center"), val_off=(3.5, 3.3, "center"))
        s.power("+3V3", s.pin(ref, 1))
        s.stub(ref, 2, net, 2.54)
    s.text("R13/R14: DNP (I2C pull-ups)", (px - 2.5, g(40) + 4 * g(10) - 3), 1.0)

    # ------------------------------------------------------------------ LED チャンネル（L / R）
    def led_channel(ch, cx, cy):
        L = ch                                  # "L" or "R"
        n = 0 if L == "L" else 1
        s.box((cx - 15.5, cy - 12.5), (cx + 52, cy + 78), f"LED channel {L}")
        # 3V3 側と 5V 側の抵抗 → 半田ジャンパー
        s.power("+3V3", (cx, cy))
        s.power("+5V", (cx + 20.32, cy))
        r3 = f"R{1 + n}"
        r5 = f"R{3 + n}"
        res(r3, "20", (cx, cy + 10.16), 0, R0603, "LED current limit @3V3 (20 ohm: 8.5/23.6/38.8 mA min/nom/max)", "0.1 W (0603)",
            ref_off=(-2.54, -1.27, "right"), val_off=(-2.54, 1.27, "right"))
        res(r5, "33", (cx + 20.32, cy + 10.16), 0, R2010, "LED current limit @5V (33 ohm 2010: 45/59/73 mA min/nom/max). Fitted, used only when SJ is set to 5V", "0.5 W (2010)",
            ref_off=(2.54, -1.27, "left"), val_off=(2.54, 1.27, "left"))
        s.wire((cx, cy), s.pin(r3, 1))
        s.wire((cx + 20.32, cy), s.pin(r5, 1))
        sj = f"SJ{1 + n}"
        s.place("Jumper:SolderJumper_3_Bridged12", sj, f"LED_{L}_SUPPLY", (cx + 10.16, cy + 22.86), 0,
                "Jumper:SolderJumper-3_P1.3mm_Bridged12_RoundedPad1.0x1.5mm",
                fields={"MPN": "solder jumper (PCB pads)", "Rating": "-",
                        "Notes": "Default: pads 1-2 bridged = 3V3 via R1/R2. For 5V: cut the 1-2 bridge, bridge 2-3 (via R3/R4)"},
                ref_off=(0, -8.0, "center"), val_off=(0, -5.0, "center"))
        s.path(s.pin(r3, 2), (cx, cy + 22.86), s.pin(sj, 1))
        s.path(s.pin(r5, 2), (cx + 20.32, cy + 22.86), s.pin(sj, 3))
        s.text("3V3", (cx - 1.0, cy + 21.3), 1.0)
        s.text("5V", (cx + 17.8, cy + 21.3), 1.0)
        # LED と MOSFET
        d = f"D{1 + n}"
        q = f"Q{1 + n}"
        s.place("Device:LED", d, "NSSW157T", (cx + 10.16, cy + 38.1), 90, "head-sensor-board:LED_Nichia_NSSW157T",
                fields={"MPN": "NSSW157T", "Manufacturer": "Nichia", "Rating": "IF 150 mA max; VF 2.8-3.4 V @80 mA; 3.0x1.4x0.52 mm",
                        "Notes": "Akizuki 116884. White chip LED, height 0.52 mm"},
                ref_off=(-8.0, -1.27, "center"), val_off=(-9.5, 1.27, "center"), datasheet="https://akizukidenshi.com/goodsaffix/nssw157t.pdf")
        s.place("head-sensor-board:Q_NMOS_GSD", q, "AO3400A", (cx + 7.62, cy + 53.34), 0, "Package_TO_SOT_SMD:SOT-23",
                fields={"MPN": "AO3400A (alt. Si2302CDS)", "Manufacturer": "Alpha & Omega (alt. Vishay)",
                        "Rating": "30 V 5.7 A VGS(th) 0.65-1.45 V RDS(on)<48 mohm @2.5 V (alt. Si2302CDS 20 V 2.6 A 0.40-0.85 V <75 mohm)",
                        "Notes": "SOT-23 pin 1=G 2=S 3=D. Gate driven by 3.3 V logic"},
                ref_off=(6.0, -1.27, "left"), val_off=(6.0, 1.27, "left"),
                datasheet="https://www.aosmd.com/res/data_sheets/AO3400A.pdf")
        s.wire(s.pin(sj, 2), s.pin(d, 2))
        s.label(f"LEDA_{L}", (cx + 10.16, cy + 30.48), "E")
        s.wire(s.pin(d, 1), s.pin(q, 3))
        s.label(f"LEDK_{L}", (cx + 10.16, cy + 44.45), "E")
        # ゲート: PWM -> 220 -> G、100k で GND
        rg, rpd, rs = f"R{5 + n}", f"R{7 + n}", f"R{9 + n}"
        res(rg, "220", (cx - 7.62, cy + 53.34), 90, R0603, "Gate series resistor (limits the gate charge peak to 15 mA)", "0.1 W (0603)",
            ref_off=(0, -3.0, "center"), val_off=(0, 3.3, "center"))
        s.wire(s.pin(rg, 2), s.pin(q, 1))
        s.label(f"GATE_{L}", (cx - 1.27, cy + 53.34), "E")
        s.stub(rg, 1, f"LED_PWM_{L}", 2.54)
        res(rpd, "100k", (cx + 2.54, cy + 62.23), 0, R0603, "Gate pull-down: LED off during reset/boot (GPIO3 is a strapping pin)", "0.1 W (0603)",
            ref_off=(-2.54, -1.27, "right"), val_off=(-2.54, 1.27, "right"))
        s.wire(s.pin(q, 1), s.pin(rpd, 1))
        s.junction(s.pin(q, 1))
        s.power("GND", s.pin(rpd, 2))
        # ソース: 1 ohm で電流検出 -> GND。TP は ILED
        res(rs, "1", (cx + 10.16, cy + 66.04), 0, R0603, "Current sense: TP ILED voltage = 1 mV per mA (1 %)", "0.1 W (0603) 1 %",
            ref_off=(2.54, -1.27, "left"), val_off=(2.54, 1.27, "left"))
        s.wire(s.pin(q, 2), s.pin(rs, 1))
        s.label(f"SENSE_{L}", (cx + 10.16, cy + 59.69), "E")
        s.power("GND", s.pin(rs, 2))
        tp = f"TP{7 + n}"
        s.place("Connector:TestPoint", tp, f"ILED_{L}", (cx + 25.4, cy + 66.04), 0, "head-sensor-board:TestPoint_Pad_D1.5mm_NoSilk",
                fields={"MPN": "test point pad", "Notes": "LED current sense node: 1 mV = 1 mA"}, in_bom=False,
                ref_off=(2.0, -5.0, "left"), val_off=(2.0, -2.6, "left"))
        s.stub(tp, 1, f"SENSE_{L}", 2.54)
        # 外付け LED 用ヘッダ
        jx = f"J{3 + n}"
        s.place("Connector_Generic:Conn_01x02", jx, f"LED_{L}_EXT (1:+ 2:-)", (cx + 36.83, cy + 38.1), 0,
                "Connector_PinHeader_2.54mm:PinHeader_1x02_P2.54mm_Vertical",
                fields={"MPN": "PinHeader 1x02 2.54 mm", "Rating": "current-limited node (after R1/R3)",
                        "Notes": "External LED: pin 1 = + (LEDA, after the series resistor), pin 2 = - (LEDK). Do NOT short + to -"},
                ref_off=(3.0, -3.5, "left"), val_off=(3.0, 6.5, "left"))
        s.stub(jx, 1, f"LEDA_{L}", 2.54)
        s.stub(jx, 2, f"LEDK_{L}", 2.54)

    led_channel("L", g(216), g(25))
    led_channel("R", g(216) + 82.55, g(25))

    # ------------------------------------------------------------------ テストポイント
    s.box((g(33), g(118)), (g(132), g(138)), "Test points")
    tps = [("TP1", "3V3", None), ("TP2", "GND", None), ("TP3", "SCL", "SCL"), ("TP4", "SDA", "SDA"),
           ("TP5", "XSHUT_L", "XSHUT_L"), ("TP6", "XSHUT_R", "XSHUT_R")]
    for i, (ref, val, net) in enumerate(tps):
        x = g(37) + i * 15.24
        s.place("Connector:TestPoint", ref, val, (x, g(128)), 0, "head-sensor-board:TestPoint_Pad_D1.5mm_NoSilk",
                fields={"MPN": "test point pad", "Notes": f"Test point {val}"}, in_bom=False,
                ref_off=(2.0, -5.0, "left"), val_off=(2.0, -2.6, "left"))
        p = s.pin(ref, 1)
        if net:
            s.stub(ref, 1, net, 2.54)
        else:
            m = (p[0], round(p[1] + 2.54, 4))
            e = (round(m[0] + 10.16, 4), m[1])
            s.path(p, m, e)
            s.power("+3V3" if val == "3V3" else "GND", e)

    # ------------------------------------------------------------------ デカップリング（3V3 と GND の間）
    s.box((g(136), g(118)), (g(194), g(138)), "Decoupling (3V3)")
    for i, (ref, val, fp, rating, note) in enumerate((
            ("C1", "10u", "Capacitor_SMD:C_0805_2012Metric", "10 V X5R 0805", "3V3 bulk: LED PWM + ToF peaks (2 x 40 mA)"),
            ("C2", "100n", "Capacitor_SMD:C_0603_1608Metric", "16 V X7R 0603", "Bypass near ToF header J1"),
            ("C3", "100n", "Capacitor_SMD:C_0603_1608Metric", "16 V X7R 0603", "Bypass near ToF header J2"))):
        x = g(142) + i * 15.24
        s.place("Device:C", ref, val, (x, g(129)), 0, fp, fields={"MPN": f"ceramic capacitor {val}F", "Rating": rating, "Notes": note},
                ref_off=(2.54, -1.27, "left"), val_off=(2.54, 1.27, "left"))
        s.power("+3V3", s.pin(ref, 1))
        s.power("GND", s.pin(ref, 2))
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

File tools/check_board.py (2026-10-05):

#!/usr/bin/env python
"""基板の追加検査（DRC では見ないもの）。KiCad 同梱の Python で実行する:

    "C:/Program Files/KiCad/10.0/bin/python.exe" tools/check_board.py [--pcb head-sensor-board.kicad_pcb]

  1. J1/J2 の各パッドのネット名・形・位置が、回路図（ネットリスト）と上面の信号名の刻印に一致するか
     （ピン 1 = 四角いパッド。刻印の並びはピン 1 から VIN, GND, SCL, SDA, XSHUT, GPIO1）
  2. 上面の刻印（文字・線）が、ランド・ヘッダの樹脂部（2.54 mm 角）・ほかの刻印・基板の縁と重ならないか（枠どうしの重なり + 余裕 0.1 mm で判定）
終了コード: 問題があれば 1。
"""
import argparse
import pathlib
import subprocess
import sys
import tempfile
import xml.etree.ElementTree as ET

import pcbnew
from pcbnew import ToMM

ROOT = pathlib.Path(__file__).resolve().parent.parent
KC = "C:/Program Files/KiCad/10.0/bin/kicad-cli.exe"
ap = argparse.ArgumentParser()
ap.add_argument("--pcb", default=str(ROOT / "head-sensor-board.kicad_pcb"))
ap.add_argument("--margin", type=float, default=0.15, help="刻印と、ほかの部品のランド・ほかの刻印の最小のすきま [mm]（JLCPCB: ランドから 0.15 mm 以内の文字は消される。文字の線の間隔は 0.15 mm より大きく）")
ap.add_argument("--housing-margin", type=float, default=0.05, help="刻印とヘッダの樹脂部の最小のすきま [mm]")
ap.add_argument("--xiao-margin", type=float, default=0.225, help="刻印と XIAO の外形（枠線の中心）の最小のすきま [mm]。枠線の太さの半分 0.075 + 0.15")
args = ap.parse_args()

TOF_NAMES = ["VIN", "GND", "SCL", "SDA", "XSHUT", "GPIO1"]
EXPECT = {
    "J1": ["+3V3", "GND", "/SCL", "/SDA", "/XSHUT_L", "/TOF_L_INT"],
    "J2": ["+3V3", "GND", "/SCL", "/SDA", "/XSHUT_R", "/TOF_R_INT"],
}
problems = []


def schematic_nets():
    """回路図から kicad-cli で出したネットリストの (部品, ピン) → ネット名。"""
    with tempfile.TemporaryDirectory() as d:
        out = pathlib.Path(d) / "n.xml"
        subprocess.run([KC, "sch", "export", "netlist", "--format", "kicadxml", "--output", str(out), str(ROOT / "head-sensor-board.kicad_sch")],
                       check=True, capture_output=True)
        root = ET.parse(out).getroot()
    m = {}
    for n in root.find("nets"):
        for node in n.findall("node"):
            m[(node.get("ref"), node.get("pin"))] = n.get("name")
    pinnames = {}
    for c in root.find("libparts") if root.find("libparts") is not None else []:
        pass
    return m


def bbox(item):
    b = item.GetBoundingBox()
    return (ToMM(b.GetLeft()), ToMM(b.GetTop()), ToMM(b.GetRight()), ToMM(b.GetBottom()))


def gap(a, b):
    """2 つの枠（x0, y0, x1, y1）のすきま。重なっていれば負。"""
    dx = max(a[0] - b[2], b[0] - a[2])
    dy = max(a[1] - b[3], b[1] - a[3])
    if dx < 0 and dy < 0:
        return max(dx, dy)
    return max(dx, dy) if (dx >= 0) != (dy >= 0) else (dx * dx + dy * dy) ** 0.5


board = pcbnew.LoadBoard(args.pcb)
sch = schematic_nets()

# ------------------------------------------------------------------ 1. J1 / J2
print("== J1 / J2: パッド ↔ 回路図のネット ↔ 刻印 ==")
silk_texts = [d for d in board.GetDrawings() if isinstance(d, pcbnew.PCB_TEXT) and d.GetLayer() == pcbnew.F_SilkS]
for ref in ("J1", "J2"):
    fp = board.FindFootprintByReference(ref)
    pads = sorted(fp.Pads(), key=lambda p: int(p.GetNumber()))
    x1 = ToMM(pads[0].GetPosition().x)
    print(f"{ref}: ピン 1 の x = {x1 - ToMM(board.GetBoundingBox().GetX()):.2f} mm（基板の左端から）, 向き {fp.GetOrientationDegrees():.0f}°")
    for p in pads:
        n = int(p.GetNumber())
        net_pcb = p.GetNetname()
        net_sch = sch.get((ref, p.GetNumber()))
        shape = "四角" if p.GetShape() == pcbnew.PAD_SHAPE_RECTANGLE else "丸"
        px, py = ToMM(p.GetPosition().x), ToMM(p.GetPosition().y)
        # このピンの刻印: 中心の x がピンの x に最も近い、J の近くの文字
        cand = [t for t in silk_texts if t.GetText() in TOF_NAMES and abs(ToMM(t.GetPosition().x) - px) < 0.2 and abs(ToMM(t.GetPosition().y) - py) < 4.0]
        label = cand[0].GetText() if cand else "（なし）"
        ok_net = net_pcb == net_sch == EXPECT[ref][n - 1]
        ok_label = label == TOF_NAMES[n - 1]
        ok_shape = (n == 1) == (p.GetShape() == pcbnew.PAD_SHAPE_RECTANGLE)
        print(f"  pin{n}: パッド {shape}  基板のネット {net_pcb:12s} 回路図のネット {str(net_sch):12s} 刻印 {label:6s}  "
              f"{'OK' if ok_net and ok_label and ok_shape else 'NG'}")
        if not (ok_net and ok_label and ok_shape):
            problems.append(f"{ref} pin{n}: net {net_pcb}/{net_sch} (expect {EXPECT[ref][n - 1]}), label {label} (expect {TOF_NAMES[n - 1]}), shape {shape}")
    xs = [ToMM(p.GetPosition().x) for p in pads]
    print(f"  ピン番号が増える向き: {'右 → 左（pin1 が右端）' if xs[0] > xs[-1] else '左 → 右（pin1 が左端）'}；刻印の並び（左から）: "
          + " ".join(t.GetText() for t in sorted([c for p in pads for c in silk_texts if c.GetText() in TOF_NAMES and abs(ToMM(c.GetPosition().x) - ToMM(p.GetPosition().x)) < 0.2 and abs(ToMM(c.GetPosition().y) - ToMM(p.GetPosition().y)) < 4.0],
                                                  key=lambda t: ToMM(t.GetPosition().x))))
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

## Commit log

2026-09-30 Stage 1: spec, parts table, LED current budget, empty KiCad 10 project
    - docs/spec.md: purpose, constraints, parts table with sources and
    confirmation status, GPIO assignment (proposal), 3V3-only LED current
    calculation (NSSW157T on 3.3 V: 8.5-38.8 mA per LED), height table,
    open questions for the user
    - README.md: progress, sources, library plan, BoardRepo note
    - tools/led_budget.py: reproducible LED / 3V3 budget calculation
    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
    [head-sensor-board.kicad_pcb, head-sensor-board.kicad_sch]
2026-09-30 Stage 2: schematic (ERC 0), custom libs, BOM, verification tools
    - Schematic (KiCad 10, A3, 40 parts): XIAO ESP32S3 on 2x7 sockets, VL53L1X
    headers J1/J2 (jumper wires; pin order is a PLACEHOLDER, unverified),
    2 LED channels (NSSW157T + AO3400A, PWM) with external LED headers J3/J4,
    per-channel solder jumper SJ1/SJ2 selecting 3V3 (R1/R2 20 ohm 0603, default)
    or 5V (R3/R4 33 ohm 2010), pull-ups (XSHUT fitted, I2C DNP), 8 test points,
    decoupling, M2 holes. Design notes with the LED / 3V3 / GPIO calculations
    are in the schematic itself.
    - ERC: 0 errors, 0 warnings; strict run (4 normally-ignored checks enabled): 0.
    - tools/check_netlist.py: 25/25 nets match the intended netlist; eve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
    [bom.csv, head-sensor-board.kicad_sch]
2026-09-30 Stage 3: board outline 40x25 mm and component placement (no routing)
    - tools/gen_pcb.py (KiCad bundled Python): builds the board from the schematic
    netlist: outline with variable W/H/corner R/hole inset, M2 holes, footprints
    with nets, symbol fields and schematic links, silkscreen labels, back legend.
    Edge usage: USB-C at the left edge, LEDs D1/D2 and external LED headers
    J3/J4 at the right/long edges, ToF headers J1/J2 on the top/bottom long
    edges, test points on the top face (ILED TPs + GND together).
    Small parts sit under the XIAO (courtyard limited to the pin-row strips).
    - DRC with schematic parity: 0 errors / 0 warnings except 64 unconnected
    items (routing is Stage 4). 40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
    [head-sensor-board.kicad_pcb, head-sensor-board.kicad_sch, pcb_template.kicad_pcb]
2026-10-01 Stage 4: 44x28 mm board, routing, DRC 0, 3D views (no gerbers/BOM/pos yet)
    - Board outline 44x28 mm (corner R1, M2 x2 unchanged); placement revised for routability
    (J1/J2 rotated so SDA/SCL match XIAO order, SJ vertical, R3/R4 split by channel, TP5/TP6 moved).
    - Silkscreen: L / R, USB-C arrow, J1/J2 six signal names (VIN GND SCL SDA XSHUT GPIO1).
    - Auto-router (tools/route.py: numpy+scipy grid Dijkstra) + apply_routes.py + make_board.py.
    Power 0.5 mm, LED current paths 0.4 mm, signals 0.25 mm, GND pour both sides, 30 vias.
    - DRC (schematic parity, --severity-all): 0 violations, 0 unconnected, 0 mismatches.
    Previously-ignored checks (missing courtyard, type/filter mismatch, via centerin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
    [head-sensor-board.kicad_pcb, head-sensor-board.kicad_sch]
2026-10-02 Stage 4 final: silkscreen cleanup, manufacturing data in gerbers/ (not ordered)
    - J1/J2 signal-name silk moved outside the header body (2.54 mm square), leader lines stop before it;
    J1/J2 pitched 0.25 mm closer to the board edge to make room. SJ and TP names also moved so
    they keep >= 0.1 mm from pads and other silk (tools/check_board.py, 137 silk items, 0 problems).
    - check_board.py also verifies J1/J2 pad nets vs the schematic netlist vs silk names.
    - gerbers/: Gerber (8 layers + job), Excellon PTH/NPTH, pos (SMD, non-DNP), BOM, ZIP, README, SHA256SUMS.
    Origin = board bottom-left. tools/verify_gerbers.py re-reads the ZIP with gerbonara and matches
    outline, 60 drill hits and copper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
    [head-sensor-board-B_Cu.gbl, head-sensor-board-B_Mask.gbs, head-sensor-board-B_Silkscreen.gbo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]
2026-10-05 Silk stroke 0.12 -> 0.15 mm for fab minimums; fab-rule check, gerber freshness check, bring-up plan
    - EXP-K-0001: published minimums of JLCPCB / PCBWay / Elecrow (silk stroke >= 0.15 mm) were not met by the
    0.12 mm silk. All silk (own text/lines and footprint outlines) is now 0.15 mm, text height stays 0.8 mm.
    Copper, mask, paste, outline and the 60 drill hits are geometrically identical to the previous gerbers
    (tools/compare_gerbers.py); only silk strokes changed. DRC 0, ERC 0, check_board OK (silk to pad >= 0.15 mm).
    - JLCPCB standard silk needs 1.0 mm text: only the "high-precision characters" option (>= 0.8 mm) passes.
    PCBWay / Elecrow / Seeed Fusion pass. Results in docs/fab_che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
    [head-sensor-board-B_Cu.gbl, head-sensor-board-B_Mask.gbs, head-sensor-board-B_Silkscreen.gbo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]
2026-10-05 Closed-loop records (.ai/): state, task graph, handoff, evidence/experiments/decisions
    State after the 2026-10-05 loop: silk 0.15 mm kept (EXP-K-0001), fab-rule/gerber-freshness checks automated,
    human gates HG-K-01..09 documented. Open: DEC-K-0004 (JLCPCB silk text height), ToF pinout, hardware bring-up.
    Not ordered. HARDWARE_VERIFIED = 0.
2026-10-28 Record: user chose JLCPCB; JLCPCB ordering facts and the open silkscreen-option sub-decision
2026-11-06 Add assembly guide (where each part goes): docs/assembly_guide.png/.md, tools/render_assembly.py
